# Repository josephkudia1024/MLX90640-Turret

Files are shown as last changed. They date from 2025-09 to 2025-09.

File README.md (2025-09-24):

# NERF Auto-Tracking Turret

An autonomous, vision-guided NERF blaster turret built from the ground up — featuring custom CAD design, thermal vision target detection, dual-core real-time control, and precision stepper-driven motion.  

This repository contains the **firmware** powering the system, designed for portability across different turret builds and hardware setups.

---

## 📂 Repository Contents

- `src/` – Source code for ESP32 firmware  
- `docs/` – Parts list, assembly/wiring diagrams, schematics, and design notes  
- `hardware/` – CAD models and reference design files

---

## 🔧 Hardware Architecture

- **Custom Structural Design**  
  - All structural components modeled in *AutoCAD Fusion*.  
  - Multiple design iterations tested for durability, stability, and cable routing.  
  - Entirely original **mechanical** and **software** integration.  

- **Power & Hardware**  
  - Central **24 V power supply** with **buck converters** regulating voltage for:  
    - Stepper motors  
    - ESP32 microcontroller  
    - Modified NERF blaster  
  - **Slip-ring integration** allows for full **360° continuous yaw rotation** while maintaining a hardwired wall connection (no reliance on onboard batteries).  

- **Control System**  
  - Dual **NEMA17 stepper motors** (pan/tilt) driven by **TB6600 drivers** for precise pitch/yaw articulation.  
  - Firing mechanism is controlled via **MOSFET**, directly linked to ESP32 logic.  

- **Sensors**  
  - **MLX90640 thermal IR sensor** (32×24 pixels @ 16 Hz).  
  - Mounted on the blaster itself for direct sightline tracking.  
  - Communicates with ESP32 over **I2C at 400 kHz**.  
  - **Target detection pipeline** includes:  
    - Weighted-centroid bounding box calculation  
    - Hot-pixel filtering  
    - Persistence logic to handle occlusions  

---

## 💻 Software Architecture

- **Development**  
  - Written in **C** using the Arduino IDE toolchain.  
  - Runs on **ESP32** using **dual-core FreeRTOS**.  

- **Multithreading**  
  - Two pinned tasks:  
    - Core 1 → Sensor acquisition + target detection  
    - Core 0 → Motion control + actuation  
  - Task synchronization achieved through **mutexes**.  

- **Motor Control**  
  - Stepper drivers actuated using **PWM step pulses**.  
  - **PID control** implemented with:  
    - Tuned Kp/Ki/Kd values  
    - Derivative damping  
    - Adaptive dead-zone scaling to suppress jitter near lock-on  

- **Targeting Logic**  
  - Defined **fire-box safety zone** ensures safe operation.  
  - If no target detected → system enters **“wander mode”**, scanning FOV until reacquisition.  
  - Fully parameterized configuration:  
    - Field of view  
    - Detection thresholds  
    - PID gains  
    - Motion profiles  

- **Portability**  
  - Designed as a **general-purpose turret control framework** that can be adapted to different:  
    - Sensors  
    - Motors  
    - Hardware platforms  

---

## 🚀 Iterations & Optimization

- Initial prototype: **Arduino Mega2560**  
- Transitioned to: **Arduino R4** (for higher clock & peripherals)  
- Final platform: **ESP32** (for dual-core processing + expanded memory)  

- **Blaster modification**:  
  - Overclocked from stock **7.4 V Li-Ion** pack → hardwired **9 V supply** for faster firing performance.  

---

## ⚡️ Features Summary

- Dual-core real-time control (FreeRTOS on ESP32)  
- Thermal-vision guided auto-tracking  
- Precision stepper motor pitch/yaw actuation  
- Safety-gated fire zone  
- Modular codebase adaptable to different builds

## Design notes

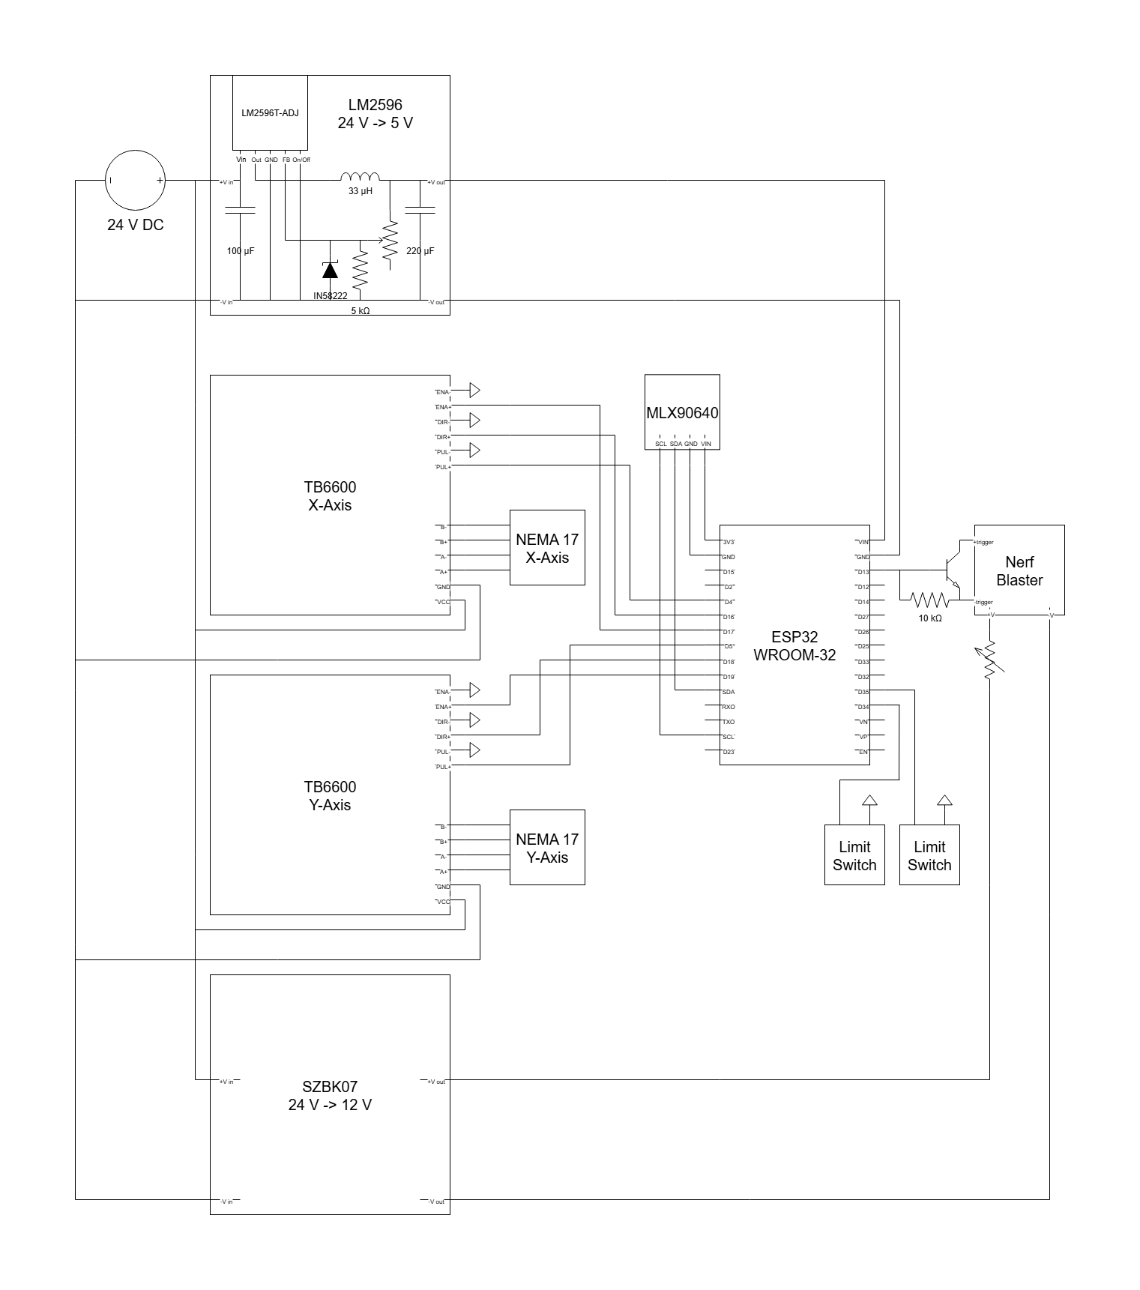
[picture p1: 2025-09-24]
docs/wd.png

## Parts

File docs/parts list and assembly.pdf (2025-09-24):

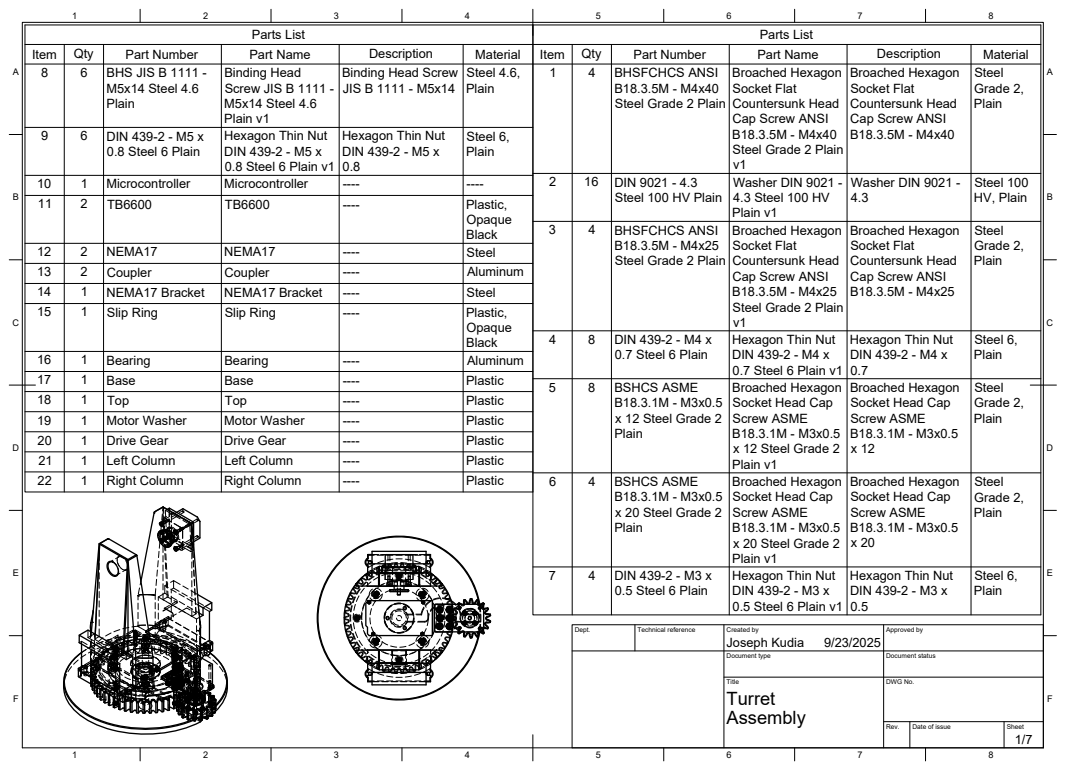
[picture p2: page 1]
Dept.; Technical reference; Created by; Approved by; Document type; Document status; Title; DWG No.; Rev.; Date of issue; Sheet; Joseph Kudia; Parts List; Item; Qty; Part Number; Part Name; Description; Material; BHSFCHCS ANSI; Grade 2,; DIN 9021 - 4.3; Washer DIN 9021 -; Steel 100 HV, Plain; DIN 439-2 - M4 x; 0.7 Steel 6 Plain; Hexagon Thin Nut DIN 439-2 - M4 x; Steel 6,; BSHCS ASME; B18.3.1M - M3x0.5 x 12 Steel Grade 2; Broached Hexagon Socket Head Cap Screw ASME B18.3.1M - M3x0.5 x 12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

Binding Head
Screw JIS B 1111 -
M5x14 Steel 4.6
Plain v1
Hexagon Thin Nut
DIN 439-2 - M5 x
0.8 Steel 6 Plain v1

Binding Head Screw
JIS B 1111 - M5x14

Broached Hexagon
Socket Flat
Countersunk Head
Cap Screw ANSI
Steel Grade 2 Plain
Washer DIN 9021 -
4.3 Steel 100 HV

Steel 100 HV Plain

DIN 439-2 - M4 x
0.7 Steel 6 Plain v1
Socket Head Cap
Screw ASME
x 12 Steel Grade 2
x 20 Steel Grade 2
DIN 439-2 - M3 x
0.5 Steel 6 Plain v1

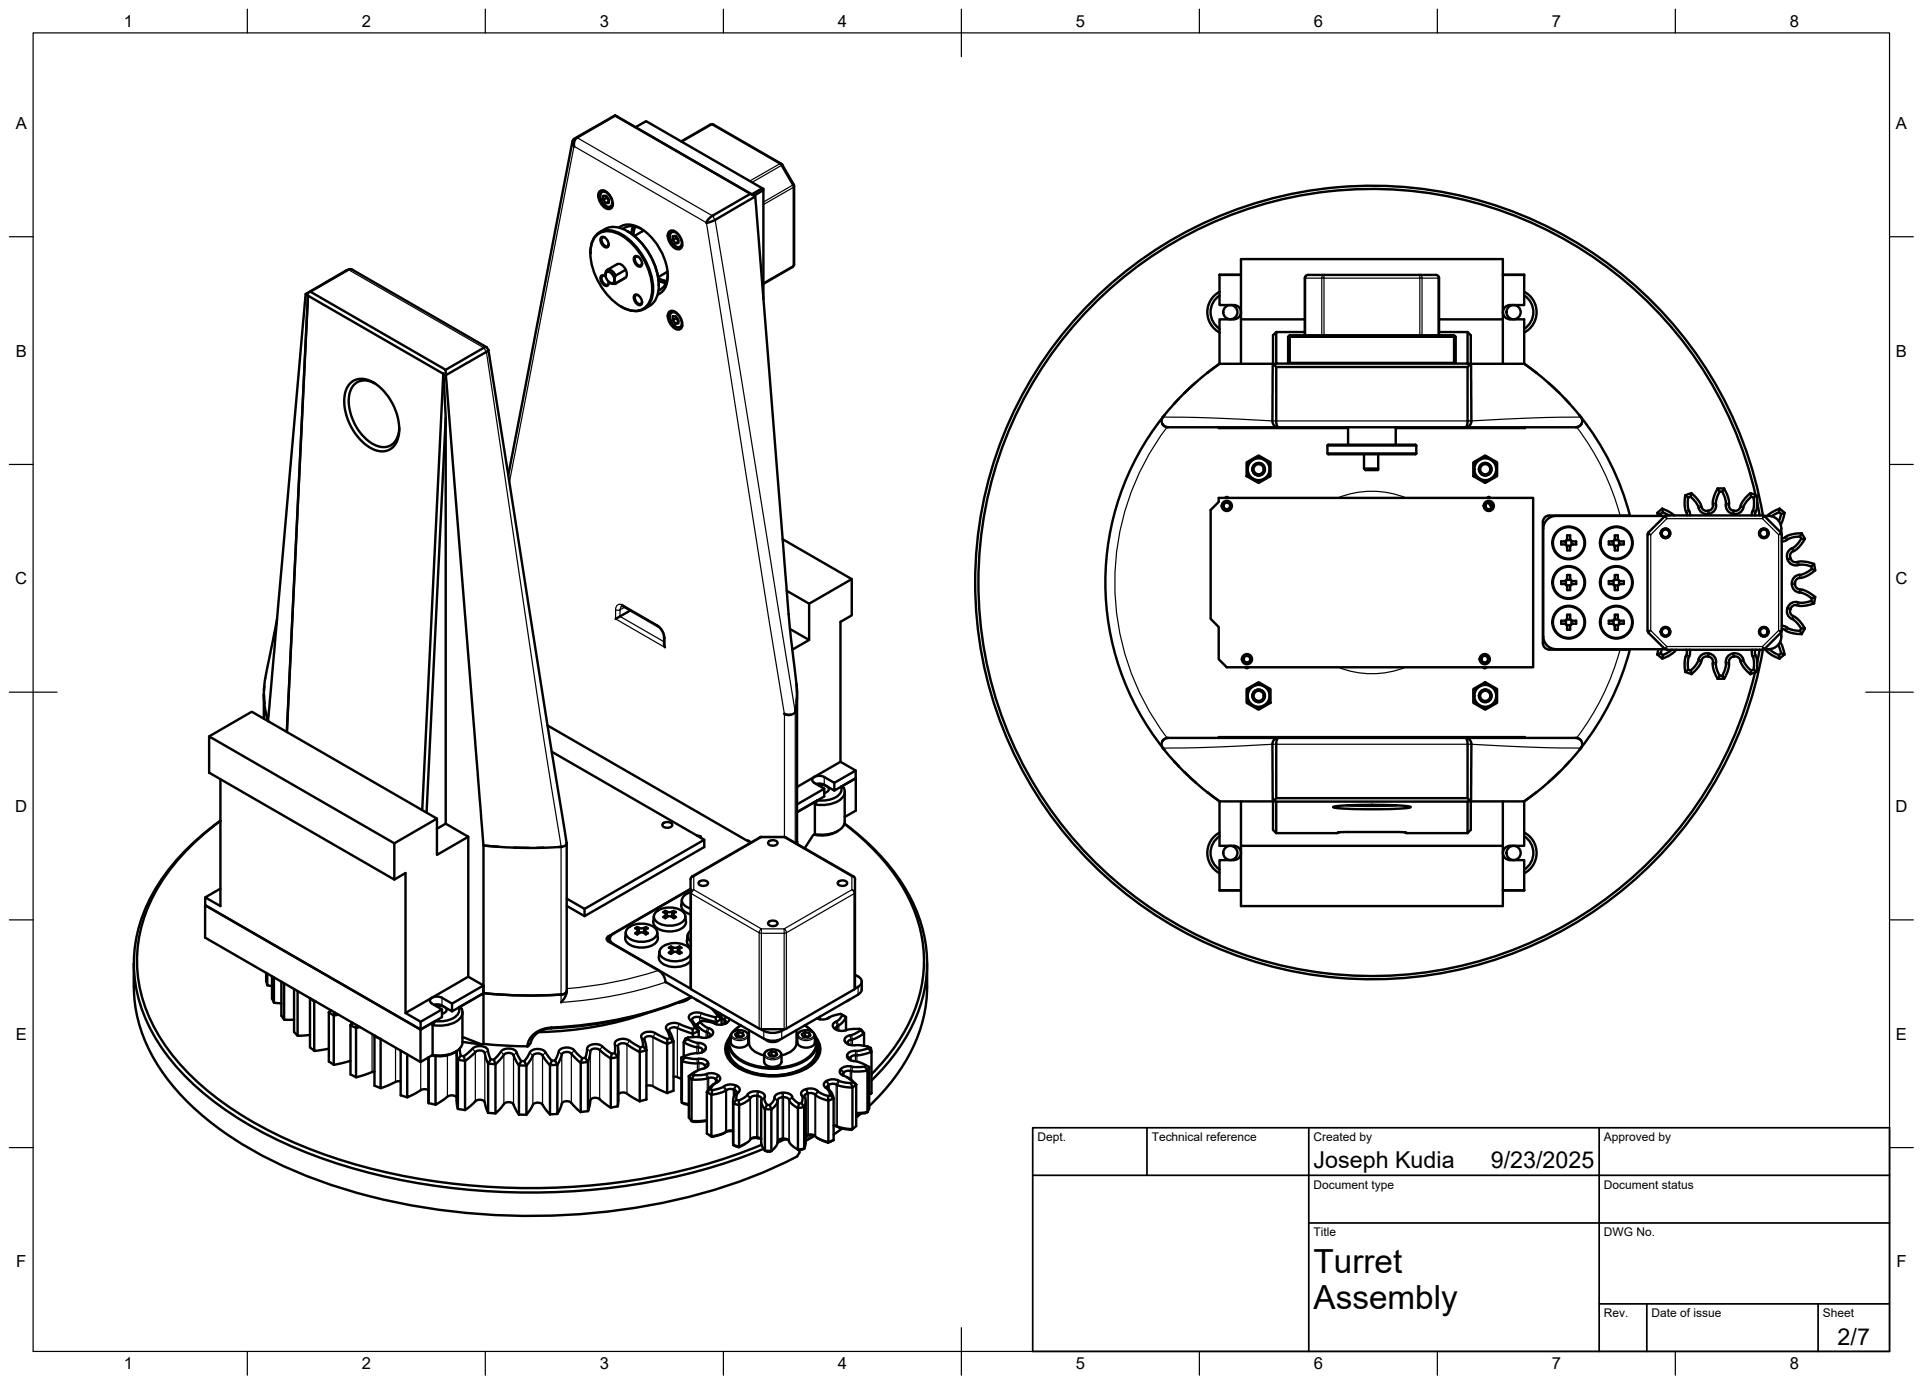
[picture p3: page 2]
Title; DWG No.

Dept. | Technical reference | Created by Joseph Kudia 9/23/2025 | Approved by

Document type | Document status

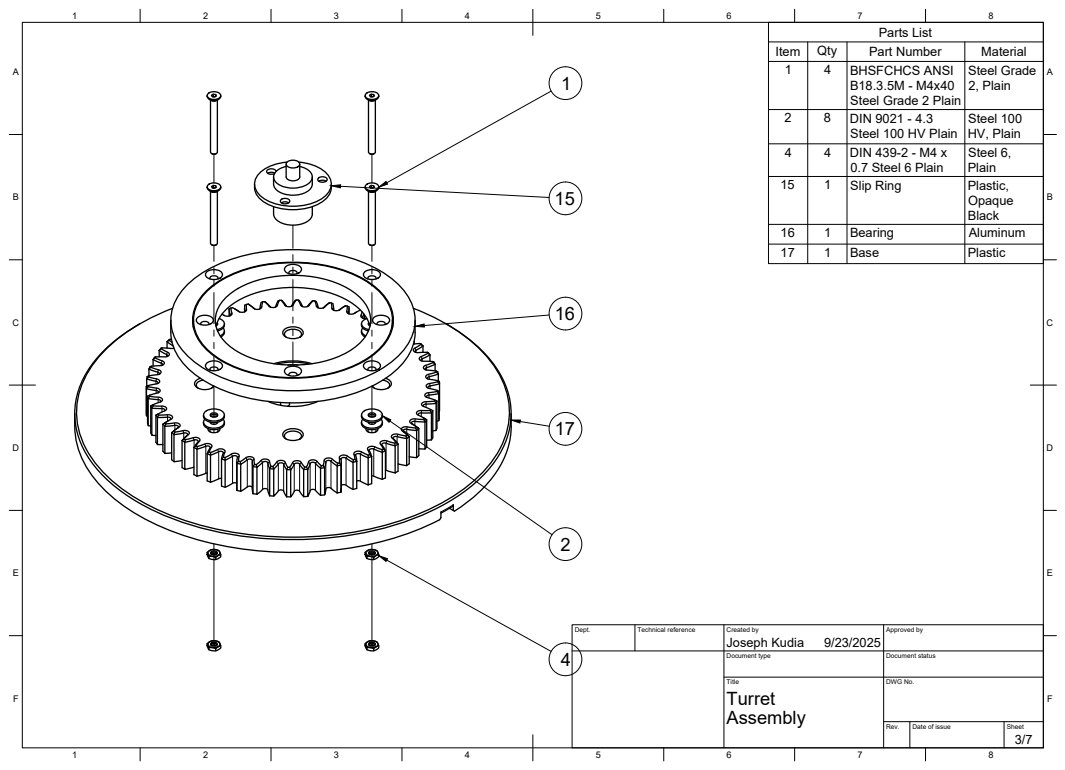
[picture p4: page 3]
8 BCDEF; ABCDEF; Title; DWG No.; Base; Plastic 4

Item | Qty 4 | BHSFCHCS ANSI Part Number | Material 1
8 | DIN 9021 - 4.3 B18.3.5M - M4x40 Steel Grade 2 Plain | Steel Grade 2, Plain 2

4 | DIN 439-2 - M4 x Steel 100 HV Plain | Steel 100 HV, Plain 4

0.7 Steel 6 Plain | Steel 6, Plain

15 | 1 | Slip Ring | Plastic, Opaque Black

16 | 1 | Bearing | Aluminum

Dept. | Technical reference | Created by Joseph Kudia 9/23/2025 | Approved by

Document type | Document status

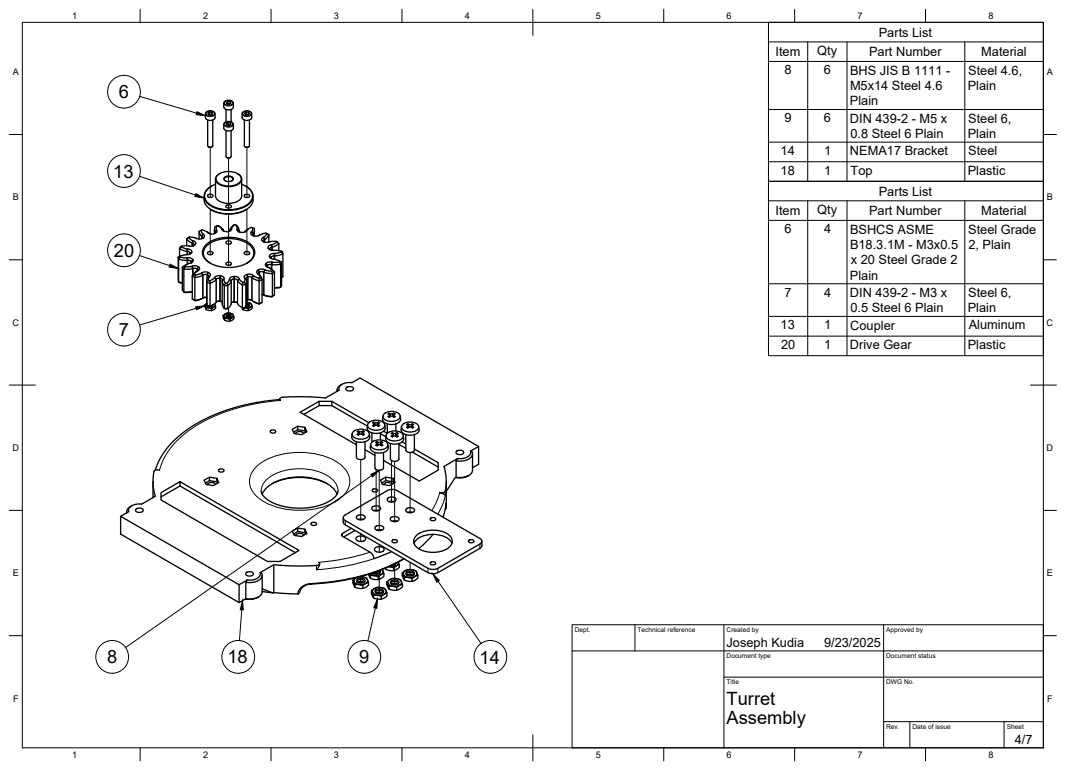
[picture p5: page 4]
Title; DWG No.; Parts List

Item | Qty | Part Number | Material
8 | 6 | BHS JIS B 1111 -M5x14 Steel 4.6 Plain | Steel 4.6, Plain

9 | 6 | DIN 439-2 - M5 x 0.8 Steel 6 Plain | Steel 6, Plain

14 | 1 | NEMA17 Bracket | Steel
18 | 1 | Top | Plastic

6 | 4 | BSHCS ASME B18.3.1M - M3x0.5 x 20 Steel Grade 2 Plain | Steel Grade 2, Plain

7 | 4 | DIN 439-2 - M3 x 0.5 Steel 6 Plain | Steel 6, Plain

13 | 1 | Coupler | Aluminum
20 | 1 | Drive Gear | Plastic

Dept. | Technical reference | Created by Joseph Kudia 9/23/2025 | Approved by

Document type | Document status

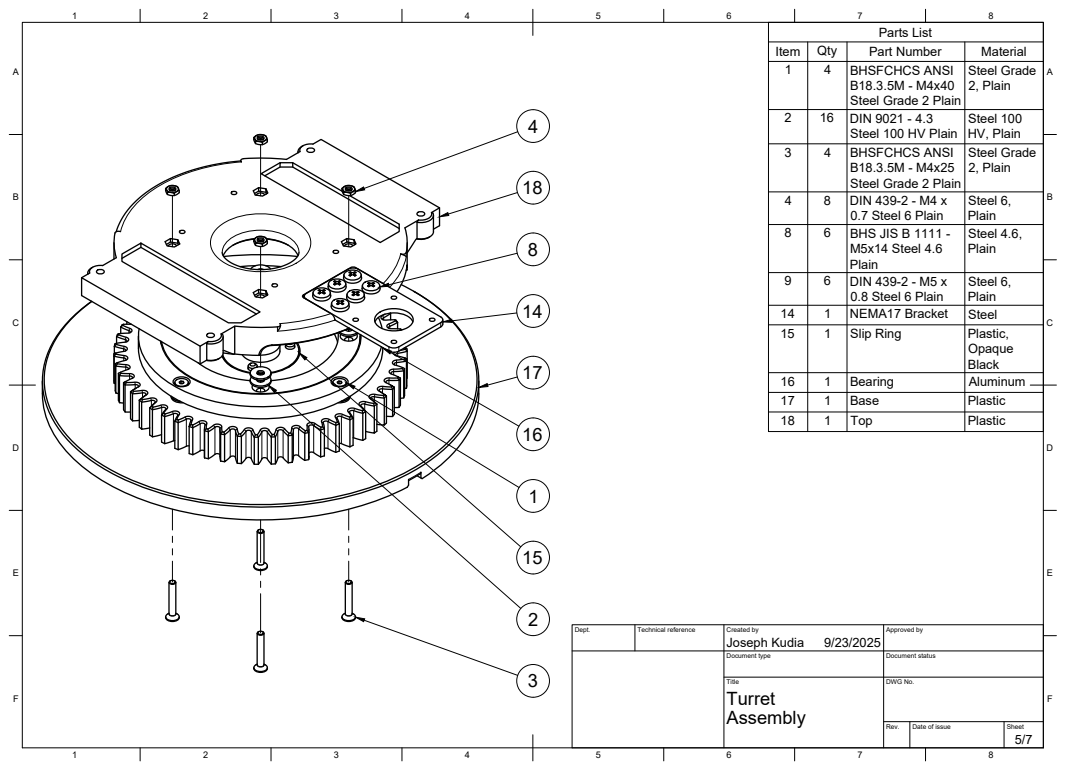
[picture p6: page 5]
8 BCDEF; ABCDEF; Title; DWG No.; Top; Plastic 32

Item | Qty 4 | BHSFCHCS ANSI Part Number | Material 1
16 | DIN 9021 - 4.3 B18.3.5M - M4x40 Steel Grade 2 Plain | Steel Grade 2, Plain 2

4 | BHSFCHCS ANSI Steel 100 HV Plain | Steel 100 HV, Plain 3

8 | DIN 439-2 - M4 x B18.3.5M - M4x25 Steel Grade 2 Plain | Steel Grade 2, Plain 4

6 | BHS JIS B 1111 -0.7 Steel 6 Plain | Steel 6, Plain 8

6 | DIN 439-2 - M5 x M5x14 Steel 4.6 Plain | Steel 4.6, Plain 9

0.8 Steel 6 Plain | Steel 6, Plain

14 | 1 | NEMA17 Bracket | Steel
15 | 1 | Slip Ring | Plastic, Opaque Black

16 | 1 | Bearing | Aluminum
17 | 1 | Base | Plastic

Dept. | Technical reference | Created by Joseph Kudia 9/23/2025 | Approved by

Document type | Document status

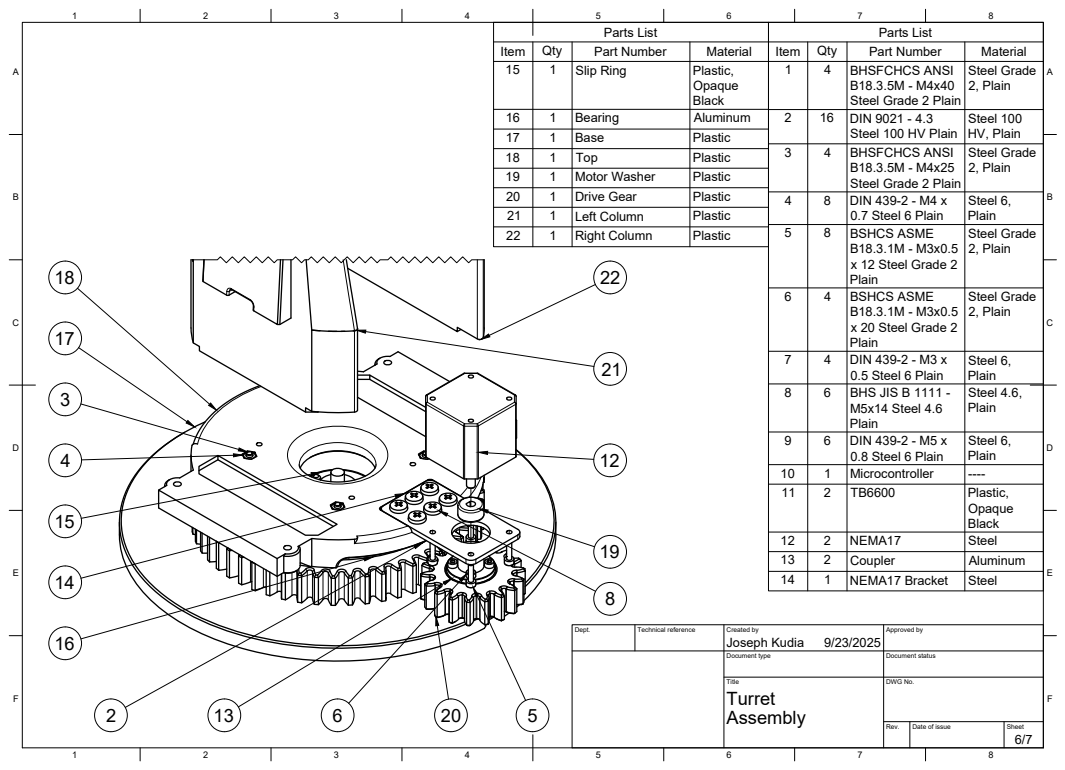
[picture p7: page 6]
8 BCDEF; ABCDEF; Title; DWG No.

Item | Qty 4 | BHSFCHCS ANSI Part Number | Material 1

15 | 1 | Slip Ring | Plastic, Opaque Black | | 16 | DIN 9021 - 4.3 B18.3.5M - M4x40 Steel Grade 2 Plain | Steel Grade 2, Plain 2

16 | 1 | Bearing | Aluminum | | 4 | BHSFCHCS ANSI Steel 100 HV Plain | Steel 100 HV, Plain 3
17 | 1 | Base | Plastic
18 | 1 | Top | Plastic
19 | 1 | Motor Washer | Plastic
20 | 1 | Drive Gear | Plastic
21 | 1 | Left Column | Plastic
22 | 1 | Right Column | Plastic

8 | DIN 439-2 - M4 x B18.3.5M - M4x25 Steel Grade 2 Plain | Steel Grade 2, Plain 4

8 | BSHCS ASME 0.7 Steel 6 Plain | Steel 6, Plain 5

4 | B18.3.1M - M3x0.5 BSHCS ASME x 12 Steel Grade 2 Plain | Steel Grade 2, Plain 6

4 | DIN 439-2 - M3 x B18.3.1M - M3x0.5 x 20 Steel Grade 2 Plain | Steel Grade 2, Plain 7

6 | BHS JIS B 1111 -0.5 Steel 6 Plain | Steel 6, Plain 8

6 | DIN 439-2 - M5 x M5x14 Steel 4.6 Plain | Steel 4.6, Plain 9

0.8 Steel 6 Plain | Steel 6, Plain

10 | 2 1 | Microcontroller TB6600 | Plastic, ---- 11

Opaque Black

12 | 2 | NEMA17 | Steel
13 | 2 | Coupler | Aluminum
14 | 1 | NEMA17 Bracket | Steel

Dept. | Technical reference | Created by Joseph Kudia 9/23/2025 | Approved by

Document type | Document status

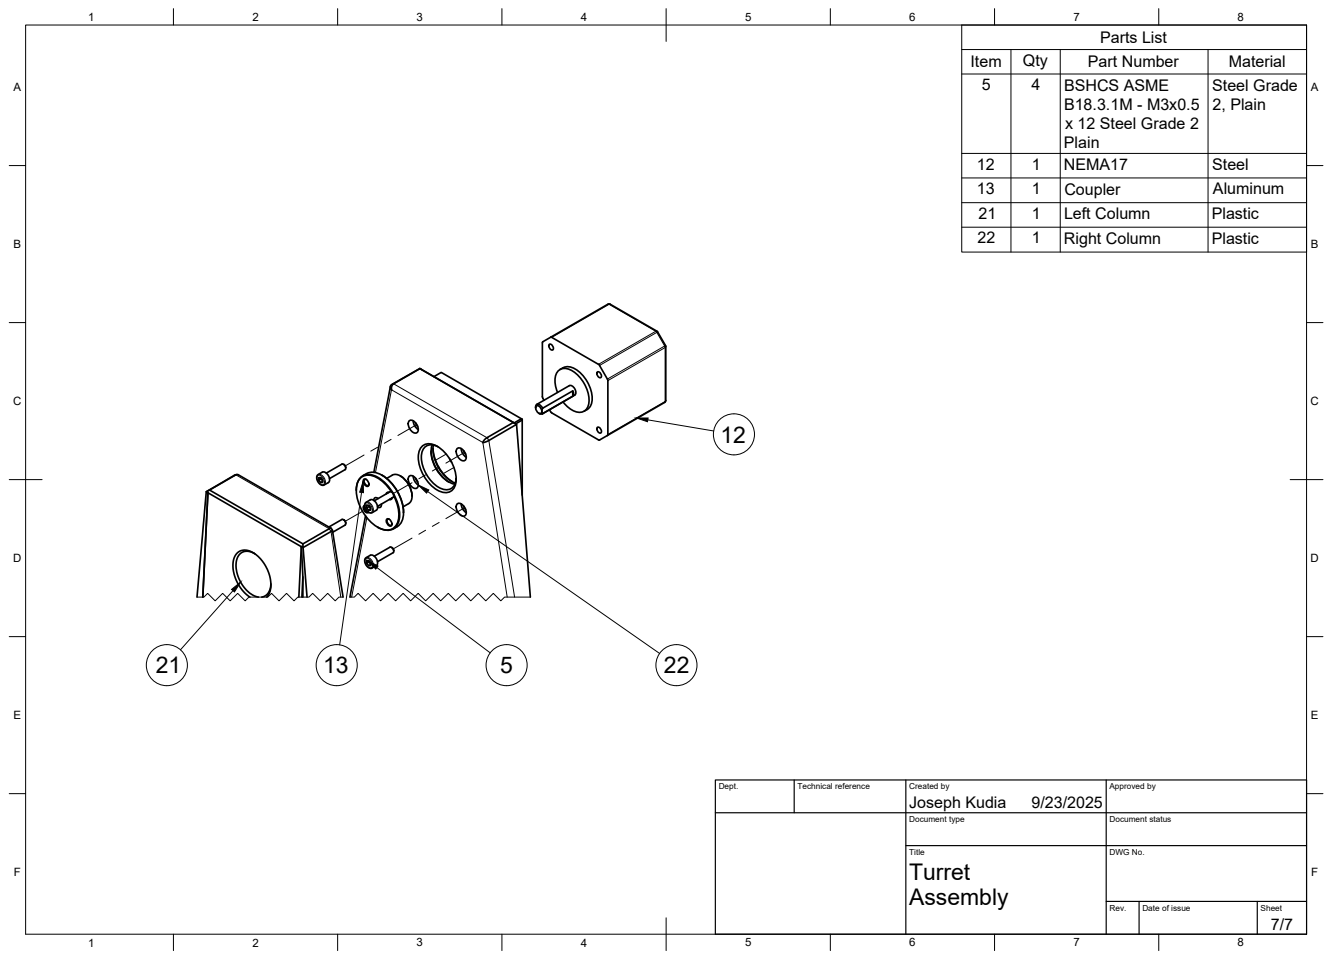
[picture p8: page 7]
Title; DWG No.

5 | 4 | BSHCS ASME B18.3.1M - M3x0.5 x 12 Steel Grade 2 Plain | Steel Grade 2, Plain

12 | 1 | NEMA17 | Steel
13 | 1 | Coupler | Aluminum
21 | 1 | Left Column | Plastic
22 | 1 | Right Column | Plastic

Dept. | Technical reference | Created by Joseph Kudia 9/23/2025 | Approved by

Document type | Document status

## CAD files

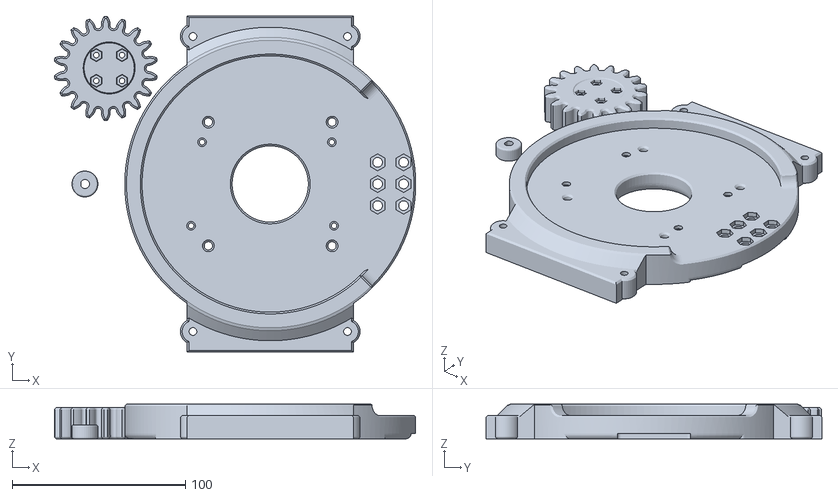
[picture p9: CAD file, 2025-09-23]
hardware/top_and_grive_gear.stl
208.7 x 194.0 x 20.0

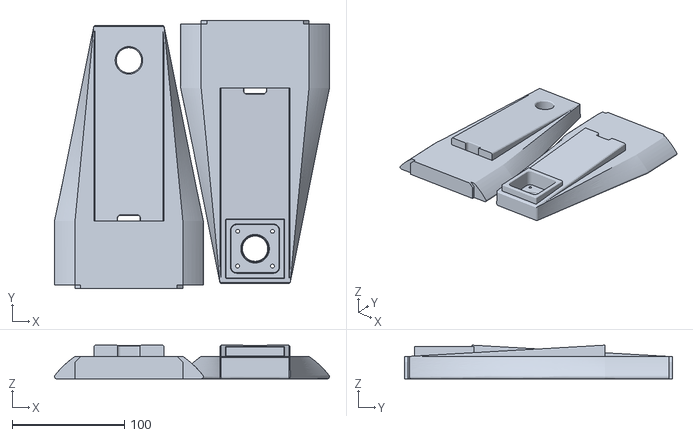
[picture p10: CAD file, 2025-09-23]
hardware/turret_columns.stl
244.8 x 238.3 x 30.0

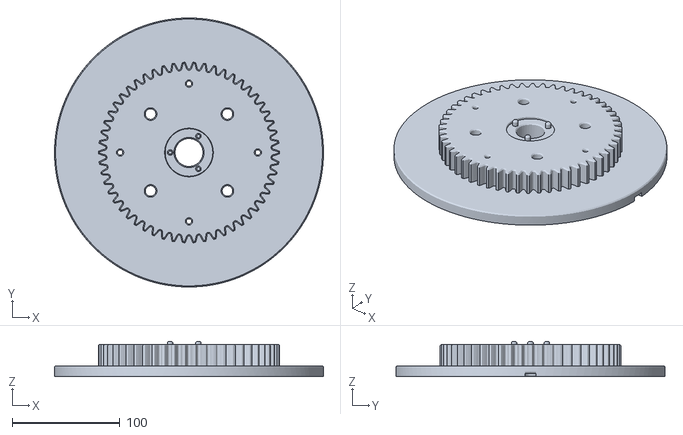
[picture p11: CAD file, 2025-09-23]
hardware/base_and_sun_gear.stl
250.0 x 250.0 x 32.6

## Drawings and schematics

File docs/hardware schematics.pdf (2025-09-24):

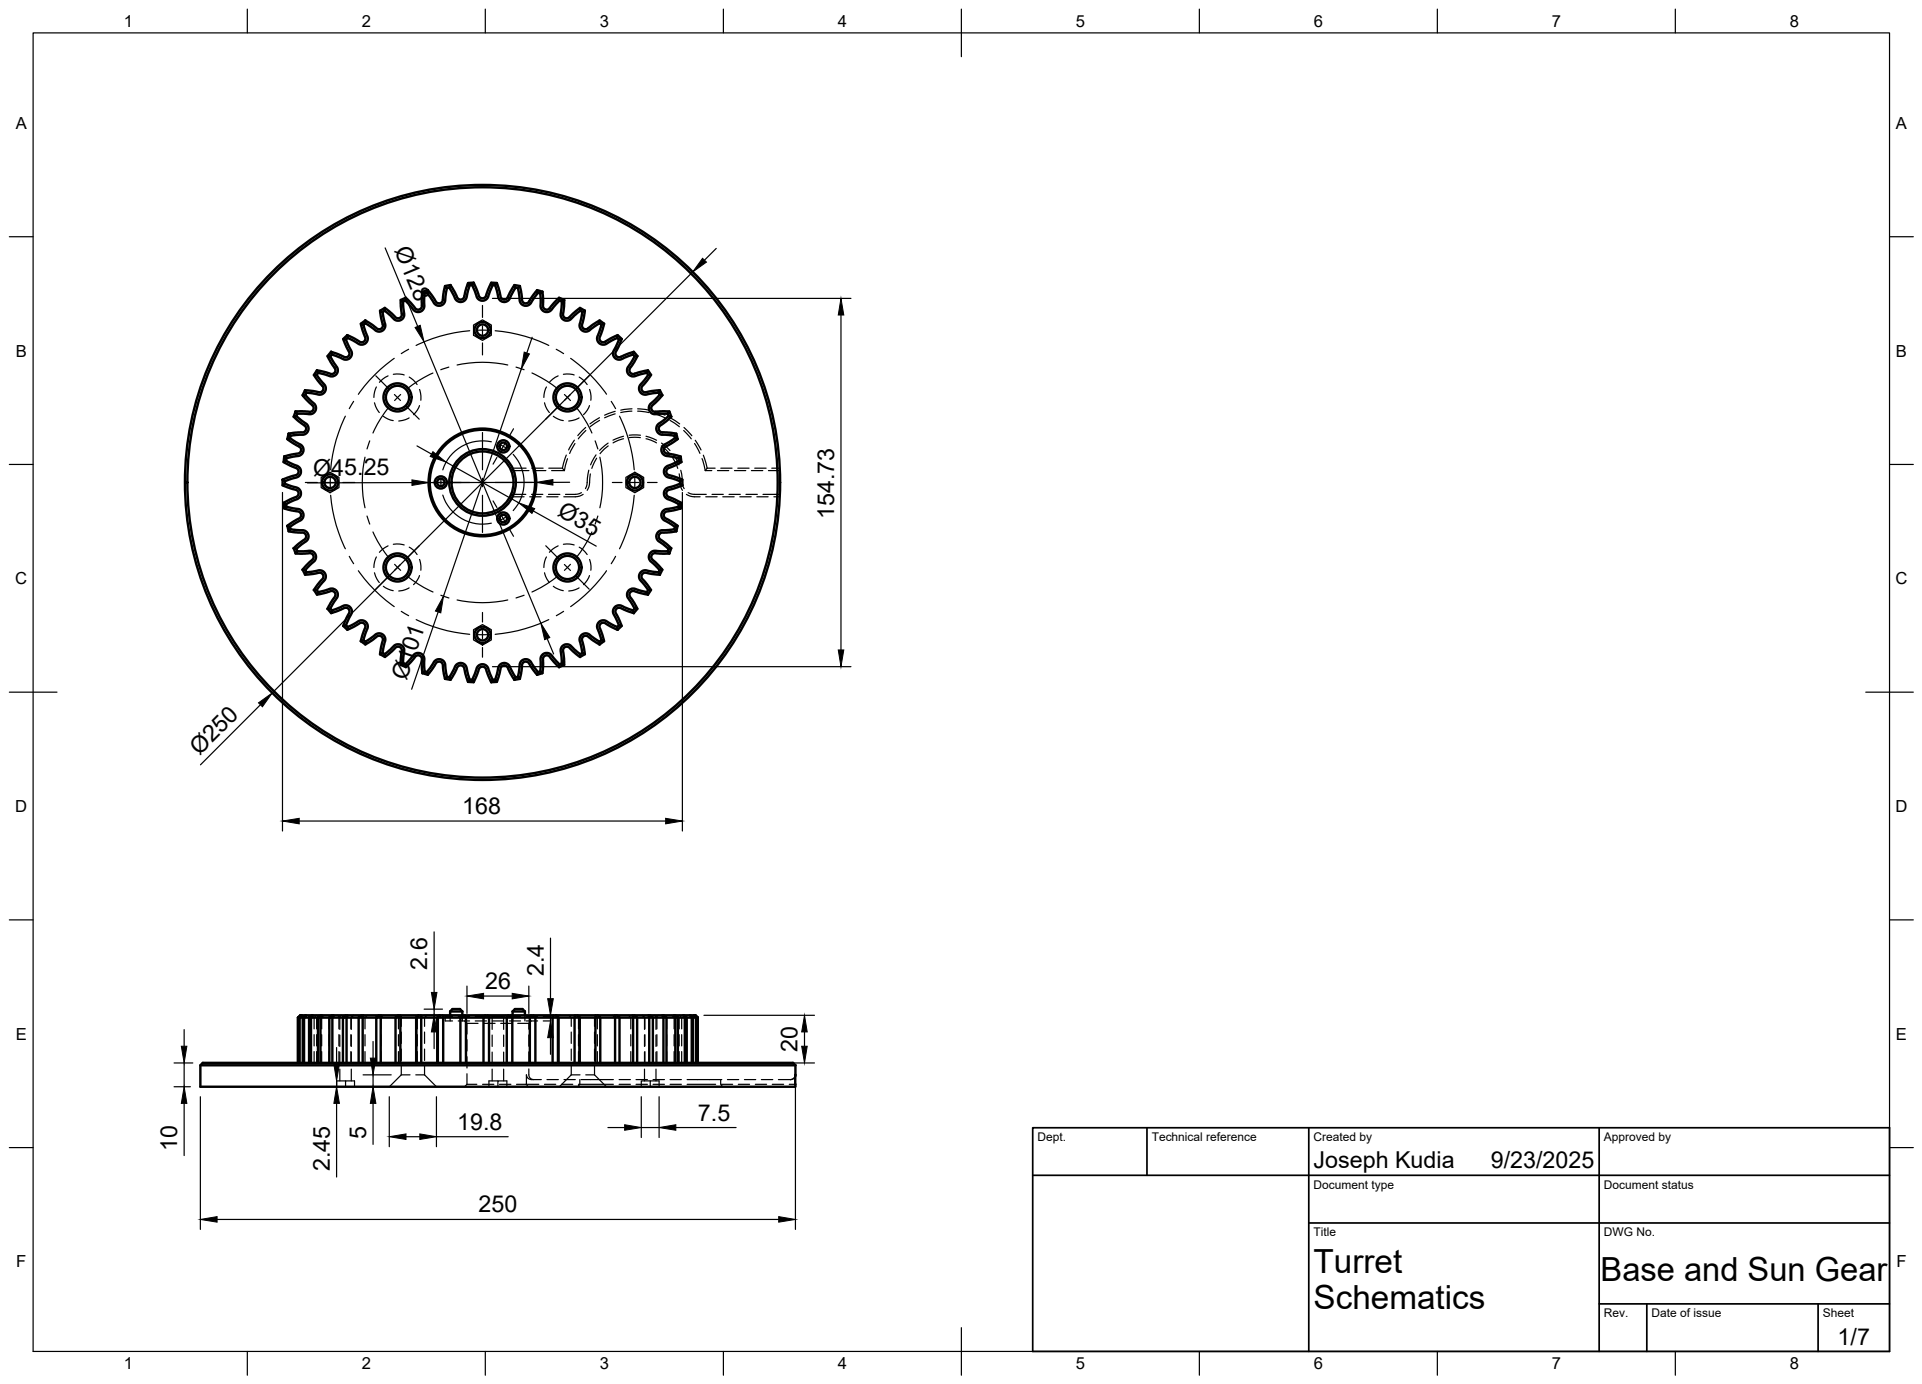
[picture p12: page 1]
Title; DWG No.; Rev.; Date of issue; Sheet; Turret; Base and Sun Gear

Dept. | Technical reference | Created by Joseph Kudia 9/23/2025 | Approved by

Document type | Document status

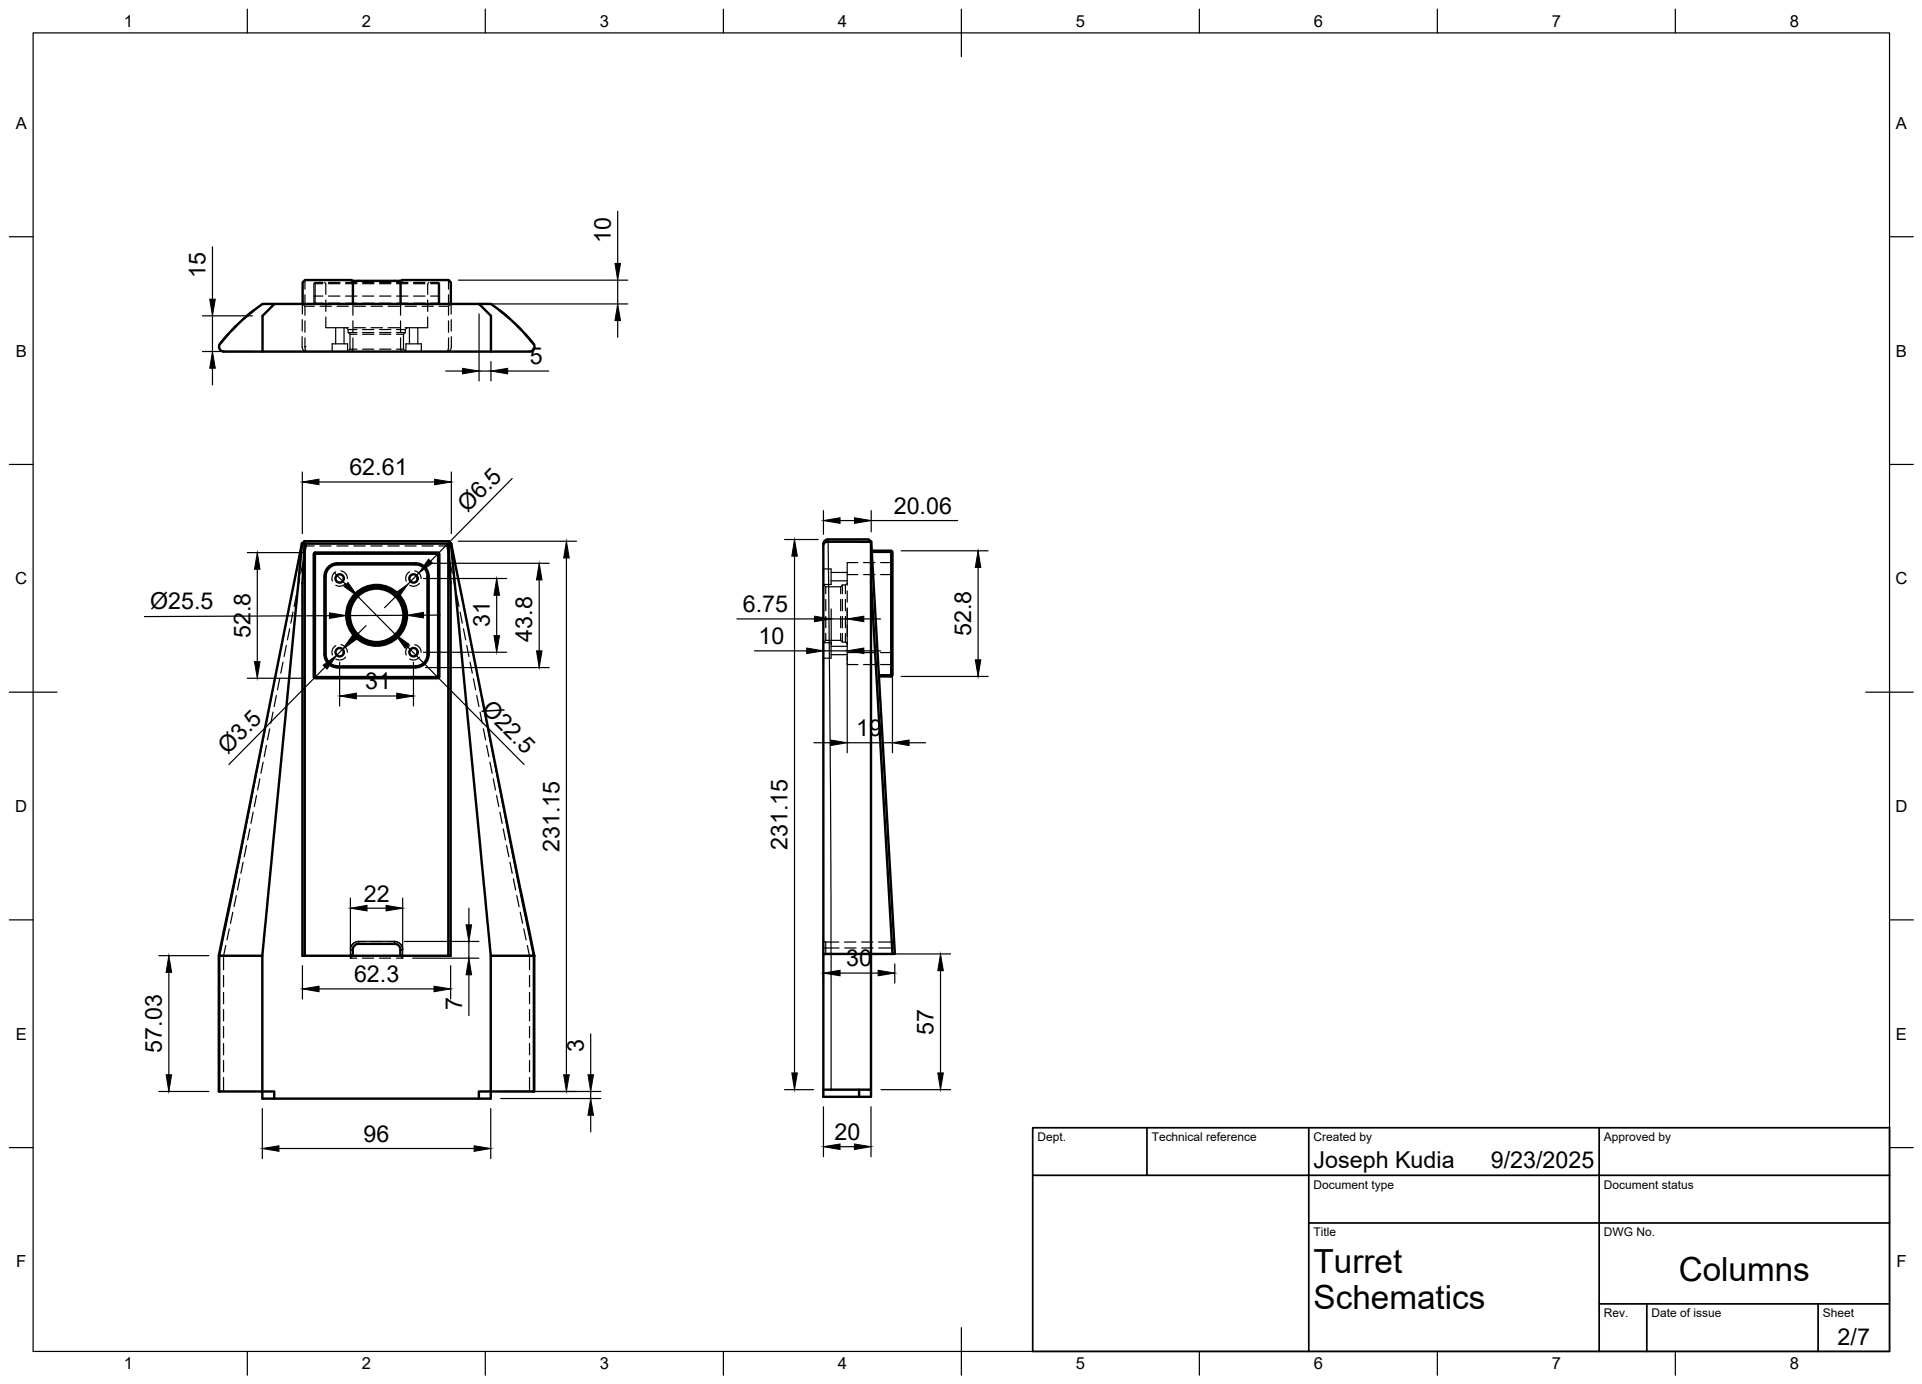
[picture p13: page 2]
Title; DWG No.; Joseph Kudia 231.15

Dept. | Technical reference | Created by 9/23/2025 | Approved by

Document type | Document status

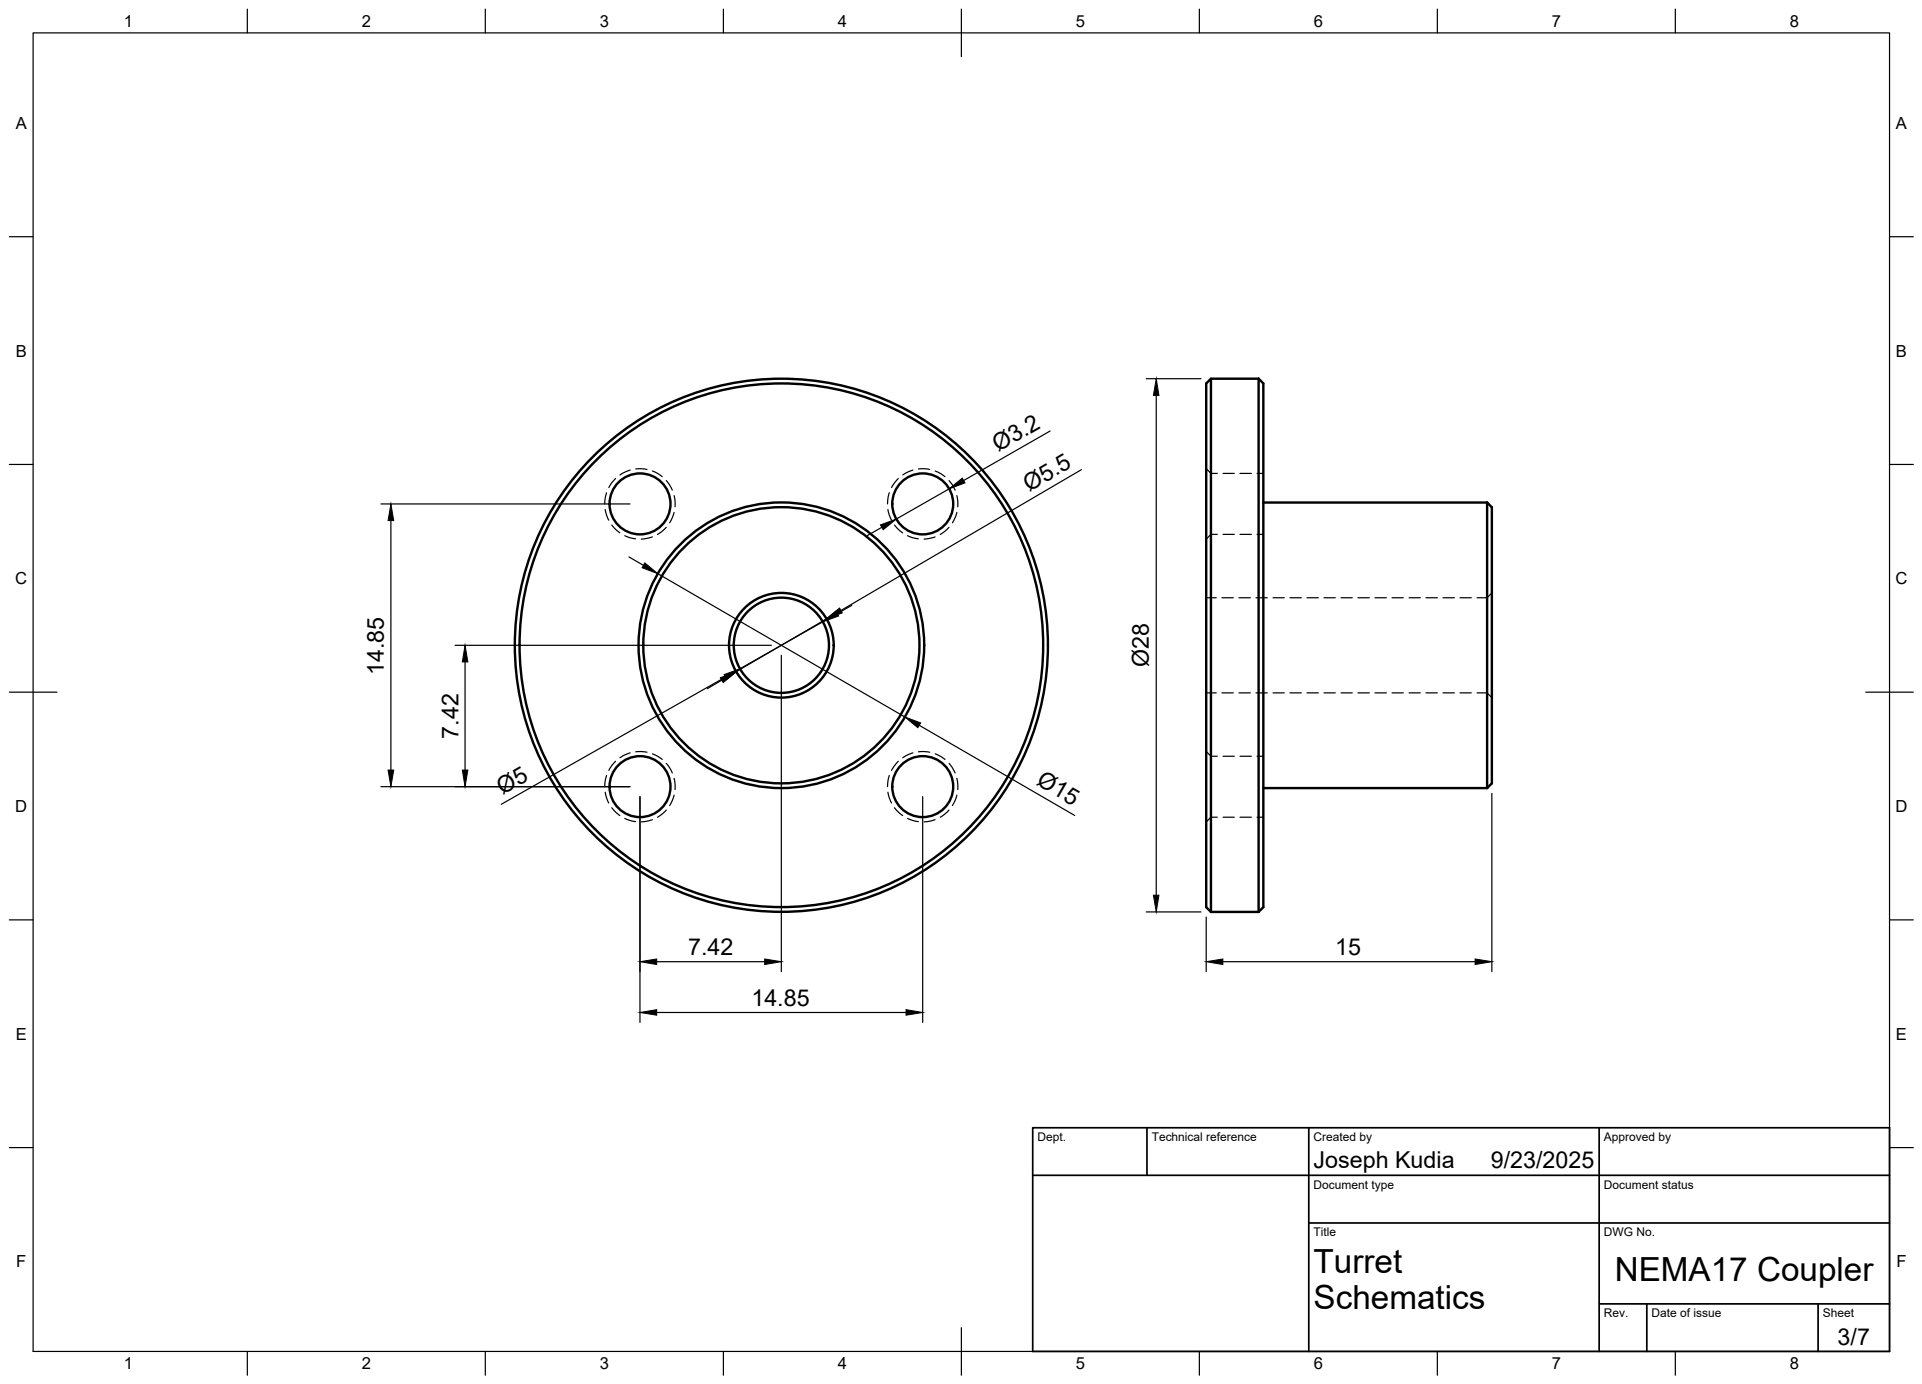
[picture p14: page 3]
Title; DWG No.; Turret; NEMA17 Coupler

Dept. | Technical reference | Created by Joseph Kudia 9/23/2025 | Approved by

Document type | Document status

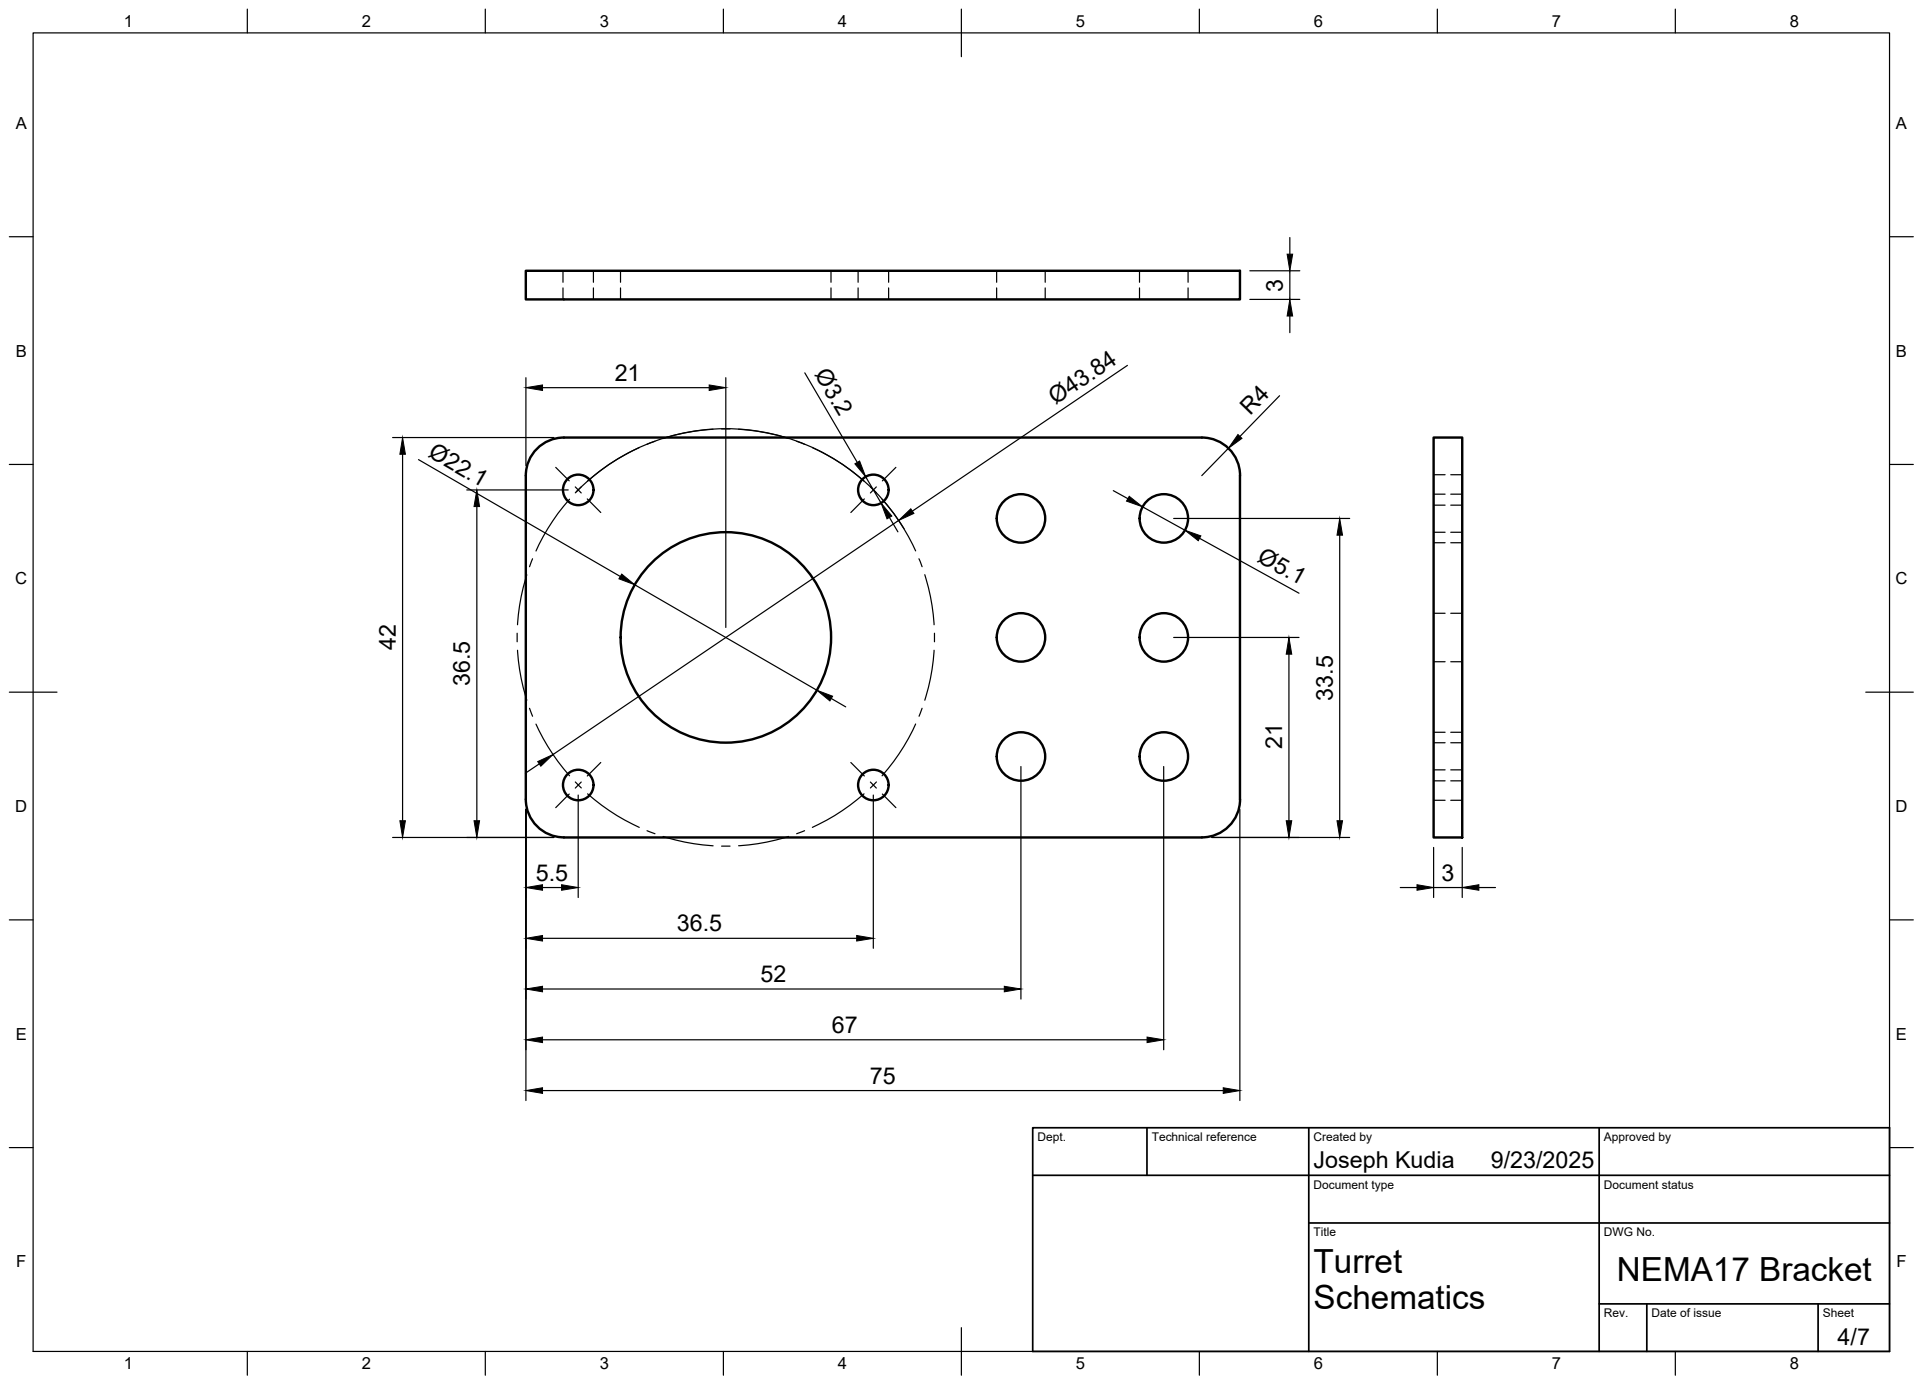
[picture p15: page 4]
Title; DWG No.; Turret; NEMA17 Bracket

Dept. | Technical reference | Created by Joseph Kudia 9/23/2025 | Approved by

Document type | Document status

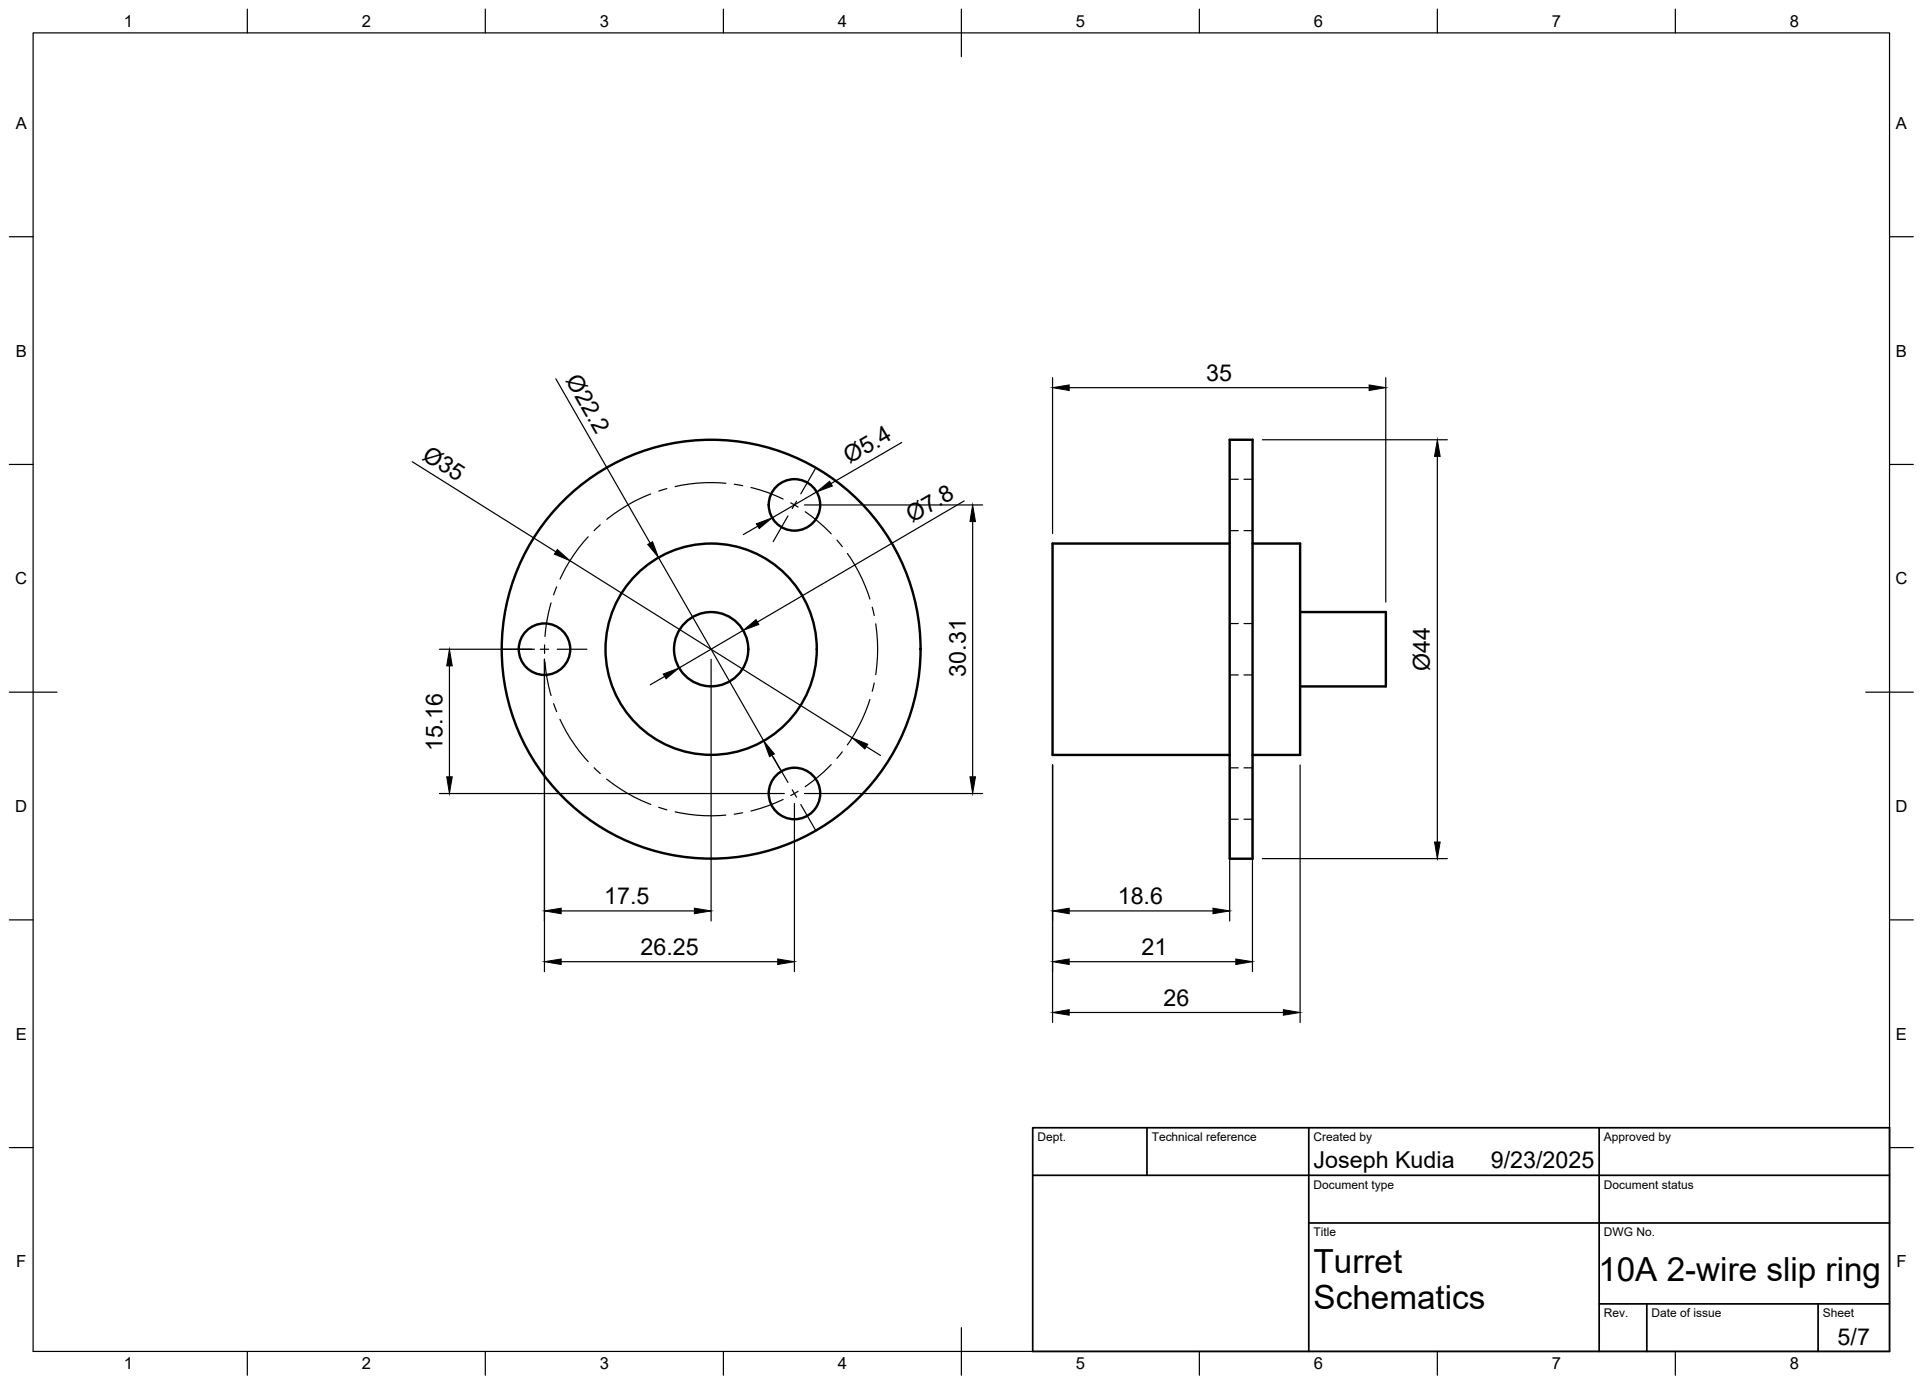
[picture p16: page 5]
Title; DWG No.; Turret; 10A 2-wire slip ring; Joseph Kudia 30.31

Dept. | Technical reference | Created by 9/23/2025 | Approved by

Document type | Document status

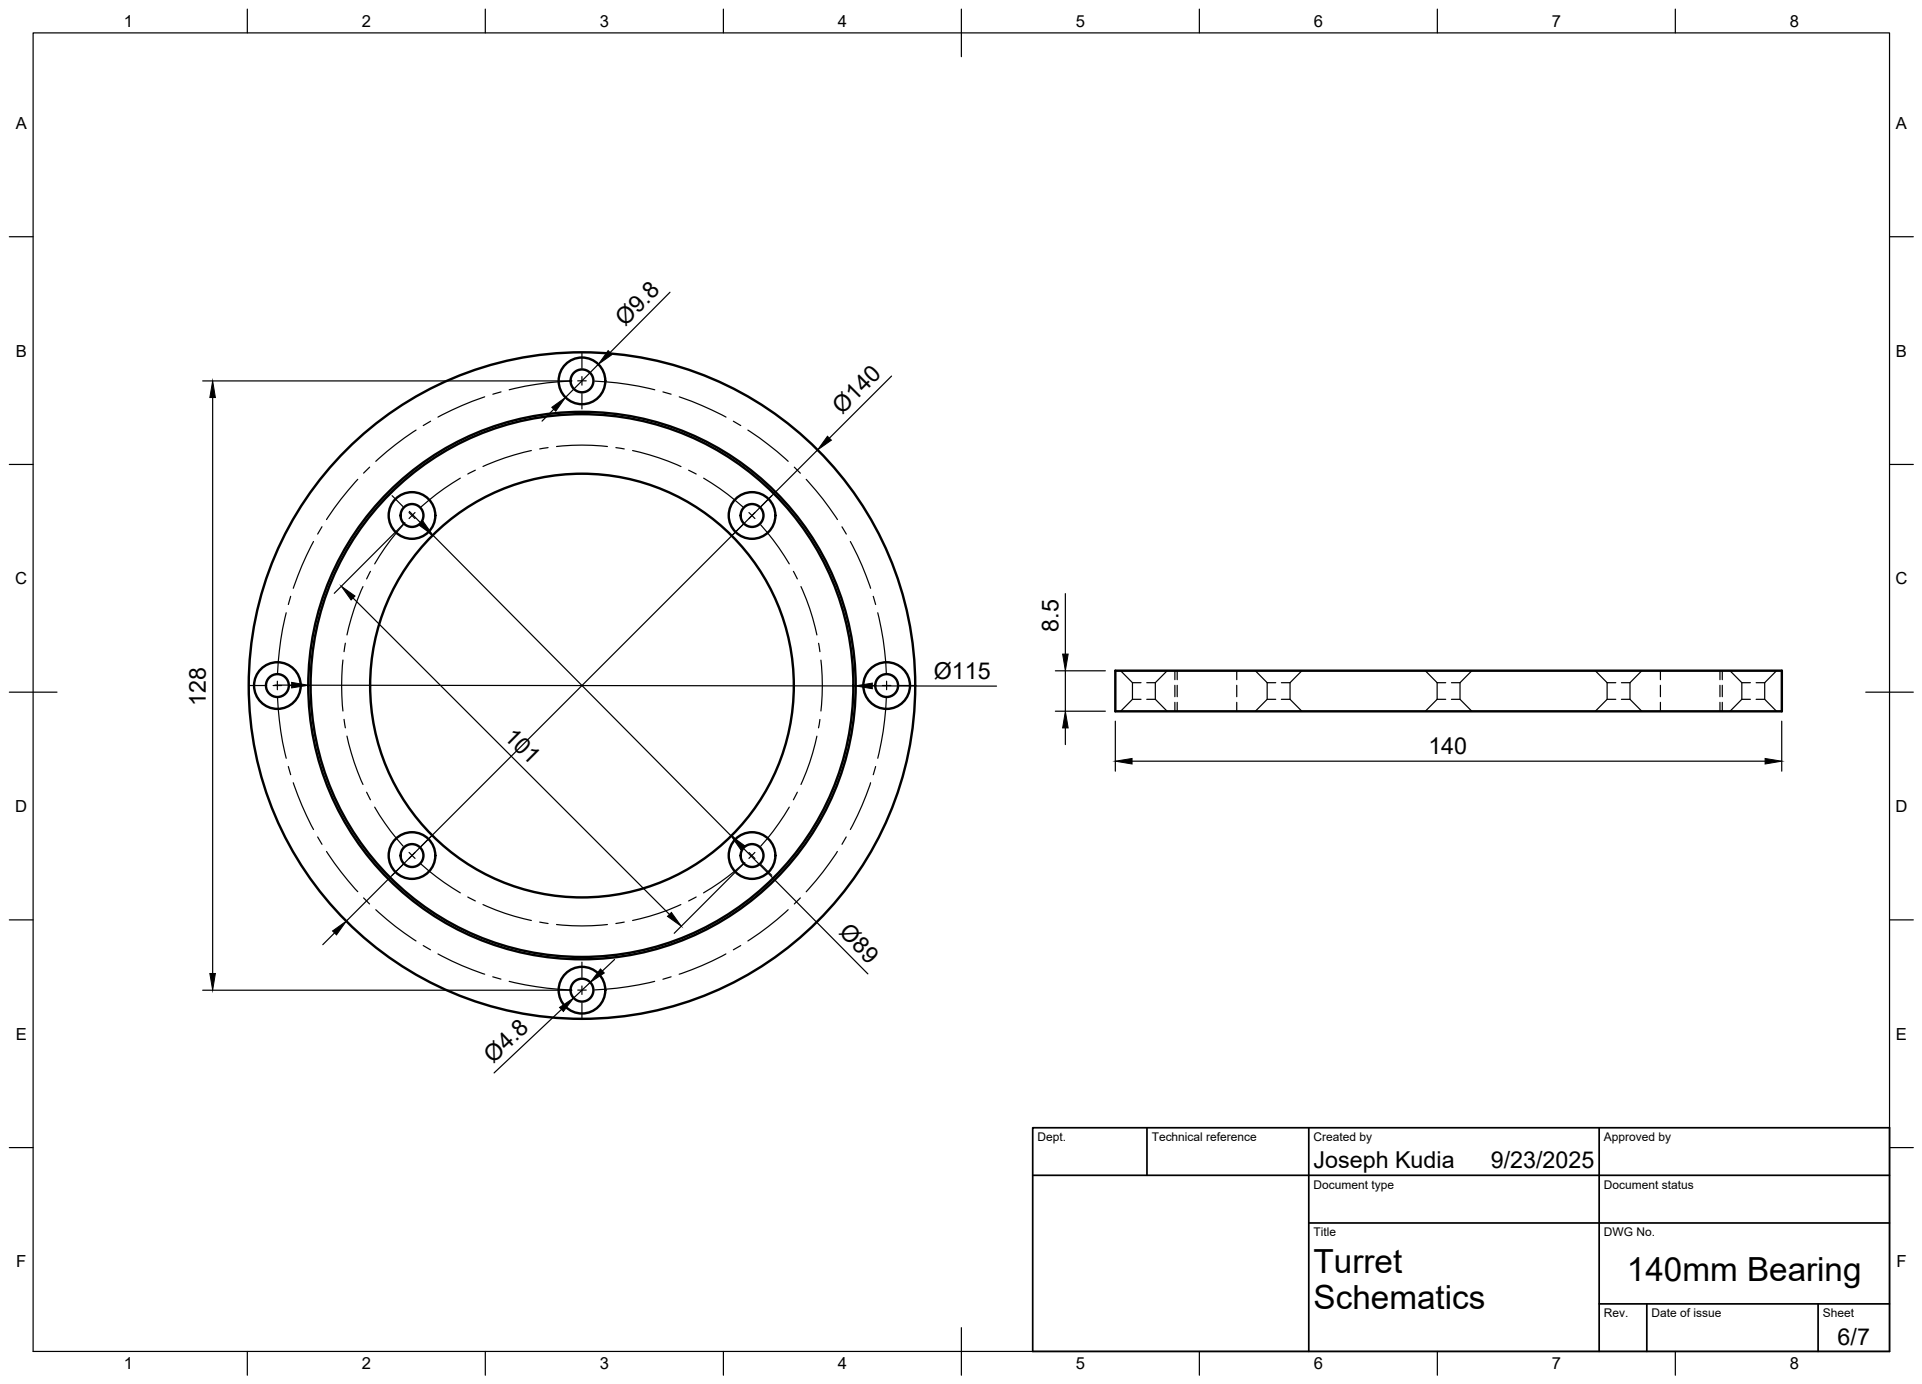
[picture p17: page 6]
Title; DWG No.; Turret; 140mm Bearing

Dept. | Technical reference | Created by Joseph Kudia 9/23/2025 | Approved by

Document type | Document status

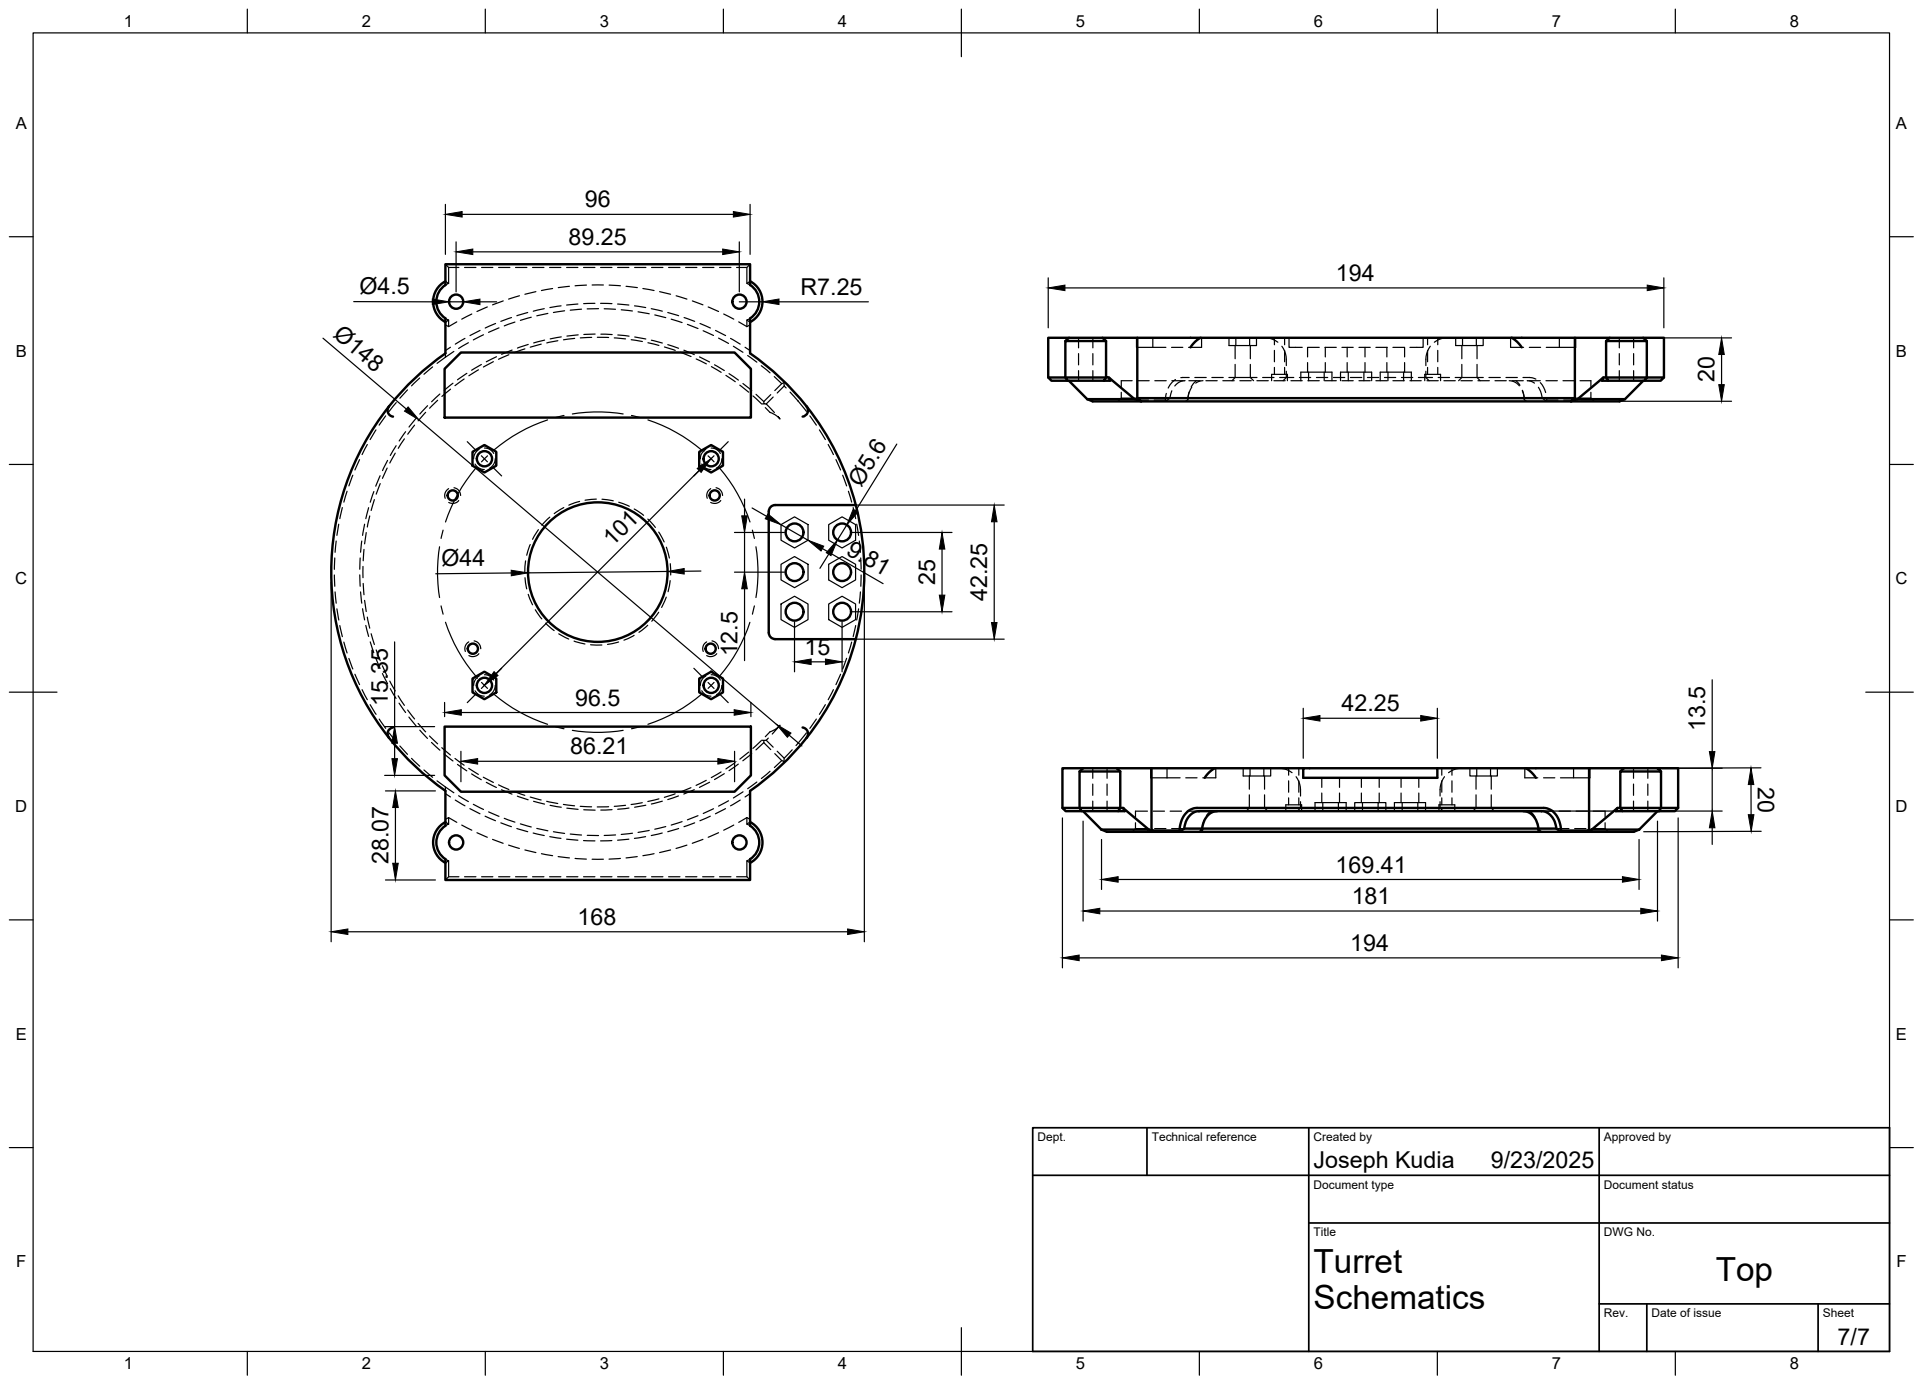
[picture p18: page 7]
8 BCDEF; ABCDEF; Title; DWG No.

Dept. | Technical reference | Created by Joseph Kudia 9/23/2025 | Approved by

Document type | Document status

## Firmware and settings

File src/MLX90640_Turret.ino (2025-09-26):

// Copyright (C) 2025 Joseph Kudia
// This project is licensed under the GNU General Public License v3.0.
// See the LICENSE file for details.

// ********************************************************************************************************************
//
// --- ESP32 Thermal Tracking Turret ---
//
// Author: Joseph Kudia
// Date Created: May 19, 2025
// Description:
// - Uses MLX90640 thermal camera to detect heat signatures
// - Controls two stepper motors (pan/tilt) with PID for smooth aiming
// - Separates camera processing and motor control onto separate cores for efficiency
// - Fires when a valid heat target is detected within a defined area
// - Created with custom parameters that enable this code to be generally applied to different turret setups / hardware
//
// ********************************************************************************************************************


#include <Adafruit_MLX90640.h>
#include <FastAccelStepper.h>
#include <freertos/FreeRTOS.h>
#include <freertos/task.h>
#include <freertos/semphr.h>


// --- EDITABLE PARAMETERS --- //

// ESP32 Pinout:
#define I2C_SDA 21
#define I2C_SCL 22

#define ENA_PIN_X 17
#define STEP_PIN_X 4
#define DIR_PIN_X 16
#define ENA_PIN_Y 19
#define STEP_PIN_Y 5
#define DIR_PIN_Y 18

#define FIRE_PIN 13
#define LED_PIN 2

// MLX90640 settings:
const int cameraPixelsX = 32, cameraPixelsY = 24;
const float cameraFOV = 55.0;
const int startupGracePeriod = 1000; // In milliseconds

const float minDetectionTemp = 30.0; // In degrees celcius
const float maxDetectionTemp = 200.0; // In degrees celcius
const int continueTrackingLostTarget = 100; // How many frames the turret will keep searching for a lost target, 0 to disable
const bool turretWandering = true; // When there is no valid target, the turret will wander clockwise looking for a target
const int wanderSpeed = 10;

// Stepper motor settings:
const float stepAngle = 1.8;
const int microstep = 32;

const bool enablePan = true;
const bool enableTilt = true;

const float maxSpeedX = 2000;
const float maxAccelX = 20000;
const int ratioX = -3; // Physical geared ratio of X stepper to turret (ratioX : 1)
const float maxSpeedY = 2000;
const float maxAccelY = 20000;
const int ratioY = 1; // Physical geared ratio of Y stepper to turret (ratioY : 1)

// PID controller parameters:
const float constX = 100.0;
const float constY = 100.0;
const float Kp_X = 1.0, Ki_X = 0.0, Kd_X = 2000.0;
const float Kp_Y = 1.0, Ki_Y = 0.0, Kd_Y = 4000.0;
const float intConstraintX = 20.0;
const float intConstraintY = 20.0;
const float deadzoneX = 1.8; // In degrees of rotation
const float deadzoneY = 1.8; // In degrees of rotation

// Firing settings:
const bool enableFiring = true;
const int firingBoxSize = 2;
const float minFiringTemp = 30.0; // In degrees celcius
const float maxFiringTemp = 200.0; // In degrees celcius

// Debug options:
const bool sendCameraFeedback = false;
const bool sendMotorFeedback = false;
const bool sendGunFeedback = false;


// --- BEGIN CODE --- //

struct Target { // Create Target struct: x and y position, w and h dimensions, and validity of target
  float x;
  float y;
  int w;
  int h;
  bool valid;
};
Target target = {0, 0, 0, 0, false};


void mlxTask(void *param);
void motorTask(void *param);
Target getAveragePos();
void fireTurret(float* frame);

// Mutex ensures safe access to the 'target' data structure between tasks on seperate cores
SemaphoreHandle_t targetMutex;
TaskHandle_t mlxTaskHandle;
TaskHandle_t motorTaskHandle;

// Initiate MLX90640
TwoWire I2CBus = TwoWire(0);
Adafruit_MLX90640 mlx;
float frame[cameraPixelsX * cameraPixelsY];

// Initiate stepper motors
FastAccelStepperEngine engine = FastAccelStepperEngine();
FastAccelStepper *stepperX = NULL;
FastAccelStepper *stepperY = NULL;


float errorX = 0, integralX = 0, derivativeX = 0;
float errorY = 0, integralY = 0, derivativeY = 0;

const float centerX = (cameraPixelsX - 1.0) / 2.0;
const float centerY = (cameraPixelsY - 1.0) / 2.0;
const float maxOutputX = Kp_X * centerX + Ki_X * intConstraintX + Kd_X * cameraPixelsX;
const float maxOutputY = Kp_Y * centerY + Ki_Y * intConstraintY + Kd_Y * cameraPixelsY;


void setup() {
  Serial.begin(921600);
  I2CBus.begin(I2C_SDA, I2C_SCL, 400000);

  if (!mlx.begin(MLX90640_I2CADDR_DEFAULT, &I2CBus)) { // Find MLX90640 on I2C Bus
    Serial.println("MLX90640 not found!");
    while (1) delay(10);
  }
  Serial.println("MLX90640 detected.");

  mlx.setMode(MLX90640_CHESS);
  mlx.setResolution(MLX90640_ADC_18BIT);
  mlx.setRefreshRate(MLX90640_16_HZ); // Set MLX90640's refresh rate to 16HZ (maximum possible refresh rate on the given hardware)

  engine.init();

  stepperX = engine.stepperConnectToPin(STEP_PIN_X);
  if (stepperX) {
    stepperX->setDirectionPin(DIR_PIN_X);
    stepperX->setEnablePin(ENA_PIN_X);
    stepperX->setAutoEnable(false);
    stepperX->setSpeedInHz(fabs(maxSpeedX * microstep * ratioX));
    stepperX->setAcceleration(maxAccelX);
  }
  stepperY = engine.stepperConnectToPin(STEP_PIN_Y);
  if (stepperY) {
    stepperY->setDirectionPin(DIR_PIN_Y);
    stepperY->setEnablePin(ENA_PIN_Y);
    stepperY->setAutoEnable(false);
    stepperY->setSpeedInHz(fabs(maxSpeedY * microstep * ratioY));
    stepperY->setAcceleration(maxAccelY);
  }

  pinMode(ENA_PIN_X, OUTPUT);
  pinMode(ENA_PIN_Y, OUTPUT);
  if (enablePan) {digitalWrite(ENA_PIN_X, LOW);}
  else {digitalWrite(ENA_PIN_X, HIGH);}
  if (enableTilt) {digitalWrite(ENA_PIN_Y, LOW);}
  else {digitalWrite(ENA_PIN_Y, HIGH);}

  pinMode(FIRE_PIN, OUTPUT);
  pinMode(2, OUTPUT);

  // Seperate MLX and motor tasks on different cores
  targetMutex = xSemaphoreCreateMutex();
  xTaskCreatePinnedToCore(
    mlxTask, "MLX90640Task", 8192, NULL, 2, &mlxTaskHandle, 1
  );
  xTaskCreatePinnedToCore(
    motorTask, "StepperMotorTask", 4096, NULL, 1, &motorTaskHandle, 0
  );
}


void loop() {vTaskDelay(portMAX_DELAY);}


// Handles MLX90640's thermal camera data capture
// Runs on Core 1 at defined refresh rate to avoid bottlenecking the motor task's speed
void mlxTask(void *param) {
  unsigned long startTime = millis();

  do { // Do not find target during grace period
    digitalWrite(FIRE_PIN, LOW);
    digitalWrite(LED_PIN, LOW);

    if (xSemaphoreTake(targetMutex, portMAX_DELAY)) {
      target = {0, 0, 0, 0, false};
      xSemaphoreGive(targetMutex);
    }

    vTaskDelay(pdMS_TO_TICKS(1));
  } while (millis() - startTime < startupGracePeriod);

  for (;;) { // Loop indefinitely on core 1 (when grace period ends)
    Target newTarget = getAveragePos(); // Find a target

    if (newTarget.valid && enableFiring) { // Check validity of target
      fireTurret(frame);
    }
    else {
      digitalWrite(FIRE_PIN, LOW);
      digitalWrite(LED_PIN, LOW);
    }

    if (xSemaphoreTake(targetMutex, portMAX_DELAY)) {
      target = newTarget;
      xSemaphoreGive(targetMutex);
    }

    vTaskDelay(pdMS_TO_TICKS(1));
  }
}


// Handles stepper motor control and PID tracking
// Runs on Core 0 to loop as fast as possible on the given hardware
void motorTask(void *param) {
  for (;;) { // Loop indefinitely
    if (xSemaphoreTake(targetMutex, portMAX_DELAY)) {
      if (target.valid) { // Check validity of target
        if (enableTilt) {digitalWrite(ENA_PIN_Y, LOW);}
        PIDController(target.x, target.y, target.w, target.h); // Move turret to target's position
      }
      else { // If target is not valid, try to find a new target
        if (turretWandering) {
          digitalWrite(ENA_PIN_Y, HIGH);
          stepperX->setSpeedInHz(fabs(wanderSpeed * microstep * ratioX));
          if (ratioX > 0) {
            stepperX->runForward();
          }
          else {
            stepperX->runBackward();
          }
        }
        else {
          stepperX->stopMove();
          stepperY->stopMove();
        }
      }
      xSemaphoreGive(targetMutex);
    }
    vTaskDelay(pdMS_TO_TICKS(1));
  }
}


// Loops through all pixels in the MLX90640's image array
// Calculates weighted centroid of hot spots to determine target position and dimensions
Target getAveragePos() {
  Target pos = {0, 0, 0, 0, false};
  static Target lastValidPos = {0, 0, 0, 0, false};
  static int missedFrameCount = 0;

  if (mlx.getFrame(frame) != 0) {
    Serial.println("Failed to get frame");
    return pos;
  }

  float maxTemp = 0;
  float weightedX = 0;
  float weightedY = 0;
  float totalWeight = 0;
  int hotPixelCount = 0;

  int minX = cameraPixelsX, maxX = 0;
  int minY = cameraPixelsY, maxY = 0;

  // Loop through MLX90640's pixel array
  for (int y = 0; y < cameraPixelsY; ++y) {
    for (int x = 0; x < cameraPixelsX; ++x) {
      int index = y * cameraPixelsX + x;
      float temp = frame[index];

      if (temp > maxTemp) { // Record the maximum detected temperature on the array
        maxTemp = temp;
      }

      if ((temp >= minDetectionTemp) && (temp <= maxDetectionTemp)) { // Check if pixel's temperature is within the detection range
        // Find the average position of the target's heat accross all pixels
        weightedX += x * temp;
        weightedY += y * temp;
        totalWeight += temp;
        hotPixelCount++;

        // Estimate target's dimensions
        if (x < minX) {minX = x;}
        if (x > maxX) {maxX = x;}
        if (y < minY) {minY = y;}
        if (y > maxY) {maxY = y;}
      }
    }
  }

  if (hotPixelCount > 0) {
    pos.x = weightedX / totalWeight;
    pos.y = weightedY / totalWeight;
    pos.w = maxX - minX + 1;
    pos.h = maxY - minY + 1;
    pos.valid = true; // Target is only valid if there is at least 1 pixel within the temperature detection range

    lastValidPos = pos;
    missedFrameCount = 0;

    if (sendCameraFeedback) {
      Serial.printf("Heat centroid: (%.2f, %.2f), Heat dimensions: (%d, %d), Max Temp: %.2f°C\n", pos.x, pos.y, pos.w, pos.h, maxTemp);
    }

    return pos;
  }
  else if (continueTrackingLostTarget > 0 && missedFrameCount != continueTrackingLostTarget && lastValidPos.valid) { // If current target is invalid and last target was valid, search for the lost target
    if (missedFrameCount < continueTrackingLostTarget) {
      missedFrameCount++;

      if (sendCameraFeedback) {
        Serial.printf("Target lost, (%d/%d)\n", missedFrameCount, continueTrackingLostTarget);
      }

      lastValidPos.y = centerY;
      return lastValidPos;
    }
    else {
      missedFrameCount = continueTrackingLostTarget;
    }
  }
  else if (sendCameraFeedback) {
    Serial.println("No hot pixels in detection range.");
  }

  return pos;
}


// PID control logic to smoothly move turret towards detected target position
// Uses proportional, integral, and derivative terms to minimize overshooting / undershooting
void PIDController(float x, float y, float w, float h) {
  static float prevErrorX = 0;
  static float prevErrorY = 0;

  errorX = centerX - x;
  errorY = centerY - y;

  integralX += errorX;
  integralY += errorY;

  derivativeX = errorX - prevErrorX;
  derivativeY = errorY - prevErrorY;

  integralX = constrain(integralX, 0, intConstraintX);
  integralY = constrain(integralY, 0, intConstraintY);

  // PID controller algorithm
  float outputX = (Kp_X * errorX + Ki_X * integralX + Kd_X * derivativeX) * ratioX * constX;
  float outputY = (Kp_Y * errorY + Ki_Y * integralY + Kd_Y * derivativeY) * ratioY * constY;

  prevErrorX = errorX;
  prevErrorY = errorY;

  float speedX = mapFloat(fabs(outputX), 0, maxOutputX, 0, maxSpeedX * microstep);
  float speedY = mapFloat(fabs(outputY), 0, maxOutputY, 0, maxSpeedY * microstep);
  // Estimate target's distance based on the 2D dimensions on MLX array
  float widthFactor = mapFloat(w, 0, cameraPixelsX, 0, 1);
  float heightFactor = mapFloat(h, 0, cameraPixelsY, 0, 1);

  if (stepperX) {
    if (fabs(errorX) * (cameraFOV / cameraPixelsX) * 2 < deadzoneX * fabs(ratioX) * widthFactor) { // If turret is already aimed at target given a certain deadzone, stop moving
      stepperX->stopMove();
      if (sendMotorFeedback) {Serial.printf("Moving Stopped\n");}
    }
    else { // Otherwise, move in accordance to the PID controller to track the target
      stepperX->setSpeedInHz(speedX);
      if (outputX < 0) {
        stepperX->runForward();
        if (sendMotorFeedback) {Serial.printf("Moving Left,  %.2lf\n", speedX);}
      }
      else if (outputX > 0) {
        stepperX->runBackward();
        if (sendMotorFeedback) {Serial.printf("Moving Right, %.2lf\n", speedX);}
      }
      else {
        stepperX->stopMove();
        if (sendMotorFeedback) {Serial.printf("Moving Stopped\n");}
      }
    }
  }
  if (stepperY) {
    if (fabs(errorY) * (0.75 * cameraFOV / cameraPixelsY) * 2 < deadzoneY * fabs(ratioY) * heightFactor) {
      stepperY->stopMove();
    }
    else {
      stepperY->setSpeedInHz(speedY);
      if (outputY < 0) {stepperY->runForward();}
      else if (outputY > 0) {stepperY->runBackward();}
      else {stepperY->stopMove();}
    }
  }
}


// Activates firing mechanism if target's heat signature is centered on the predefined firing area
void fireTurret(float* frame) {
  int halfSize = firingBoxSize / 2;

  int centerX = cameraPixelsX / 2;
  int centerY = cameraPixelsY / 2;

  int startX = centerX - halfSize;
  int startY = centerY - halfSize;

  for (int y = startY; y < startY + firingBoxSize; y++) {
    for (int x = startX; x < startX + firingBoxSize; x++) {
      if (x < 0 || x >= cameraPixelsX || y < 0 || y >= cameraPixelsY) {continue;} // If target is within the firing box, fire the turret
      float temp = frame[y * cameraPixelsX + x];
      if (temp >= minFiringTemp && temp <= maxFiringTemp) { // Verify target is within the temperature detection range
        digitalWrite(FIRE_PIN, HIGH);
        digitalWrite(LED_PIN, HIGH);
        if (sendGunFeedback) {Serial.printf("Turret Firing\n");}
        return;
      }
    }
  }

  digitalWrite(FIRE_PIN, LOW);
  digitalWrite(LED_PIN, LOW);

  if (sendGunFeedback) {Serial.printf("Turret Stopping\n");}
}


float mapFloat(float x, float in_min, float in_max, float out_min, float out_max) {
  // Custom float version of Arduino's map() function; scales values proportionally to a given range, works with float values
  return (x - in_min) * (out_max - out_min) / (in_max - in_min) + out_min;
}

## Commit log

2025-09-23 add stl files
    [base_and_sun_gear.stl, top_and_grive_gear.stl, turret_columns.stl]
2025-09-24 added schematics
2025-09-24 updated schematics
2025-09-24 Rename assembly.pdf to parts and assembly.pdf
2025-09-24 Rename turret.drawio.png to wiring diagram.png
2025-09-24 Rename wiring diagram (1).png to wiring diagram.png
2025-09-24 Rename wd.png to wiring diagram.png
2025-09-24 Rename parts and assembly.pdf to parts and assembly diagrams.pdf
2025-09-24 Rename parts and assembly diagrams.pdf to parts list and assembly diagrams.pdf
2025-09-24 Rename parts list and assembly diagrams.pdf to parts list and assembly.pdf
